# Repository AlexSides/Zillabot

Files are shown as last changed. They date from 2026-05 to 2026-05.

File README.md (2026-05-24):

# ZillaBot Senior Design Portfolio

ZillaBot is an autonomous senior design robot built for sumo-style pushing and tug-of-war competition. The robot combines a two-wheel rear-drive platform, floor-facing boundary sensors, front-facing time-of-flight sensors, IMU feedback, a custom CAD chassis, and an integrated PCB to support real-time navigation decisions.

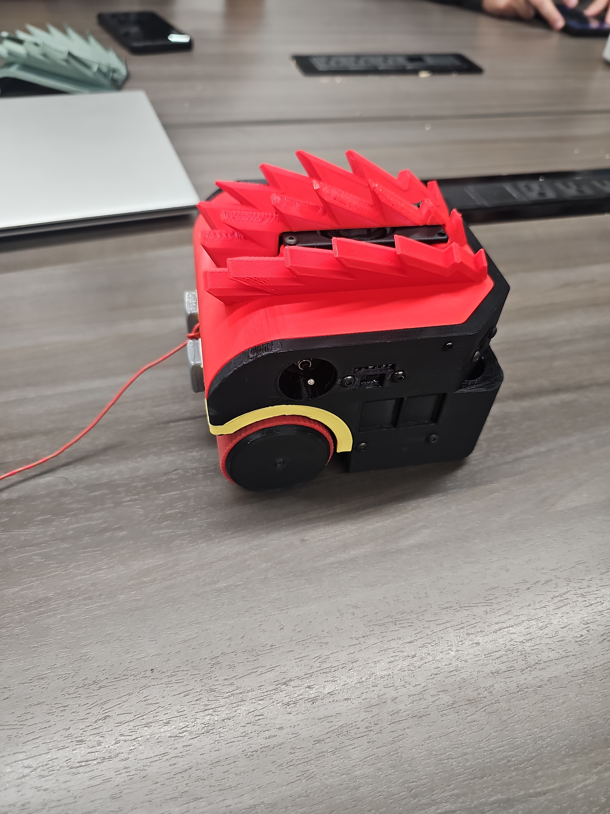
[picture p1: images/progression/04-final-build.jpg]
Final ZillaBot build


## What This Repository Shows

- Autonomous robot design for sumo and tug-of-war match formats
- Mechanical progression from breadboard prototype to enclosed 3D-printed robot
- Sensor-driven navigation using boundary, object-detection, and orientation inputs
- PCB, CAD, and chassis assets from the senior design build
- Test evidence, demo videos, and selected code examples

## Project Highlights

| Area | Evidence |
| --- | --- |
| Final robot build | [Build progression gallery](docs/media-gallery.md) |
| Demo footage | [Video evidence](docs/media-gallery.md#demo-videos) |
| Chassis and enclosure design | [Hardware assets](docs/hardware-assets.md) |
| PCB and wiring architecture | [PCB layout image](images/design/pcb-layout.png) and [Gerber package](hardware/pcb/zillabot-gerber.zip) |
| Architecture diagrams | [Rendered system and state diagrams](docs/architecture-diagrams.md) |
| Bill of materials | [BOM and cost summary](docs/bill-of-materials.md) |
| Navigation design | [Navigation subsystem](docs/navigation-subsystem.md), [state machine snippet](code-snippets/navigation-state-machine.md), and [source walkthrough](docs/source-code-walkthrough.md) |
| Testing summary | [Testing results](docs/testing-results.md) |

## Testing Evidence

The [testing results](docs/testing-results.md) page summarizes available subsystem, demo, and traction/push-test evidence. The revised tighter and thicker silicone tread improved push-test pass rates across the tested loads, though the new tread results used a smaller sample size and should be read with that limitation in mind.

## Key Engineering Takeaways

- Stronger traction can improve pushing force but also changes navigation behavior.
- Boundary detection needs to remain the highest-priority safety behavior.
- Live telemetry made sensor and state debugging easier during integration.
- Dual-core organization helped separate fast safety/motor behavior from higher-level navigation.
- Real-world robot testing revealed issues that were not obvious from code alone.

## Visual Design Progression

| Prototype wiring | Integrated prototype | Final enclosure |
| --- | --- | --- |
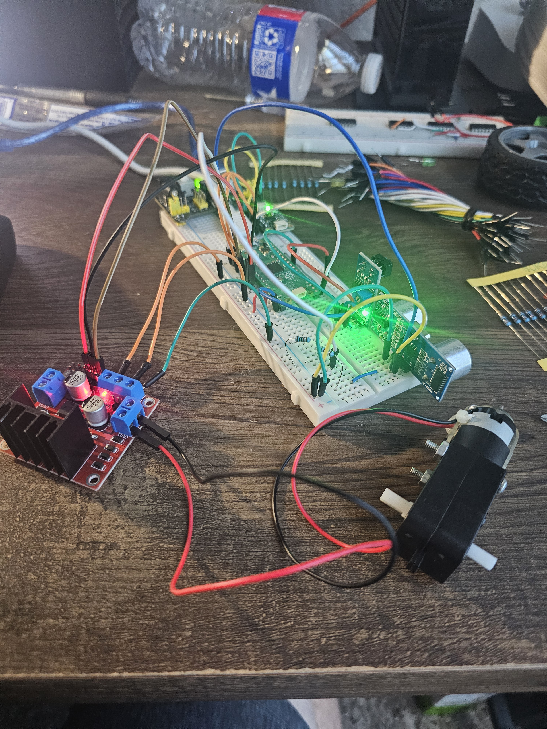
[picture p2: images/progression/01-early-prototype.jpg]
Early breadboard prototype
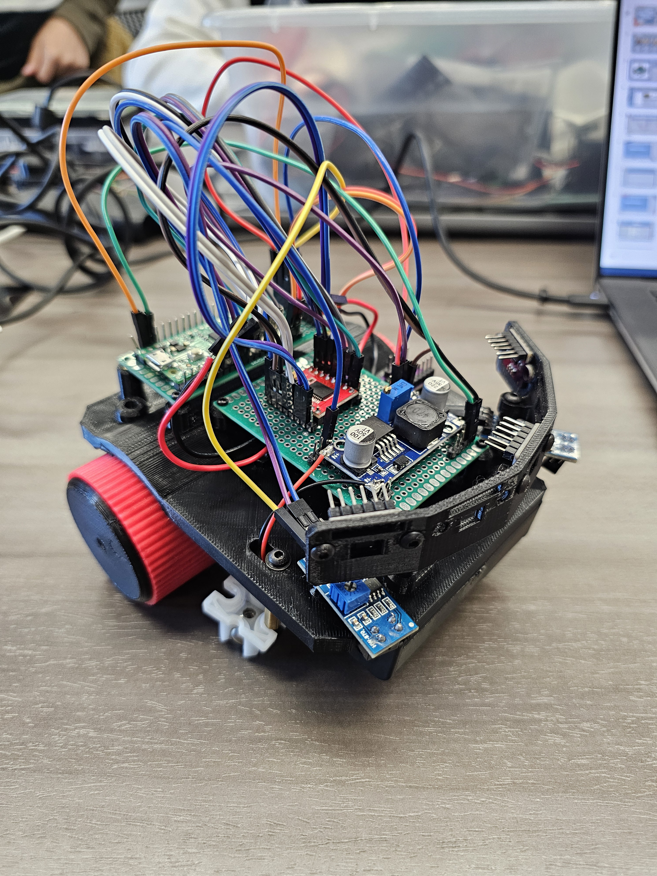
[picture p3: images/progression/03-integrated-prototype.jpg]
Integrated prototype
|  |  | Final enclosed ZillaBot |

## Repository Structure

- `docs/` contains the project overview, subsystem writeups, media gallery, hardware asset index, testing notes, and reflection.
- `images/` contains build photos, CAD renders, PCB imagery, chassis revisions, architecture diagrams, and testing visuals.
- `videos/` contains short demo clips.
- `hardware/` contains selected CAD, drawing, and PCB fabrication assets.
- `code-snippets/` contains portfolio-friendly excerpts that explain important logic.
- Root Python files contain the public project source snapshot included with this portfolio.

## Demo Videos

- [April 13 demo run](videos/2026-04-13-demo-run.mp4)
- [May 10 competition run](videos/2026-05-10-competition-run.mp4)
- [Short demonstration clip](videos/short-demo-clip.mp4)

## Current Status

This repository contains the public project source snapshot, selected hardware assets, photos, demo videos, and documentation from the ZillaBot senior design build. Some performance areas were documented qualitatively when formal measured data was not available.

## Wi-Fi Secrets

This repo does not track `wifi_secrets.py`.

Create a local `wifi_secrets.py` from `wifi_secrets.example.py` only when you are ready to run telemetry locally.

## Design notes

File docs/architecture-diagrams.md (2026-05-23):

# Architecture Diagrams

This page provides GitHub-viewable PNG versions of the system and navigation diagrams. The PNGs are exported from the D2 project-management and design-review materials.

The original editable sources remain available here:

- [IDR / design-review Draw.io source](../diagrams/idr-presentation.drawio)
- [Poster Draw.io source](../diagrams/poster.drawio)

## Top-Level System

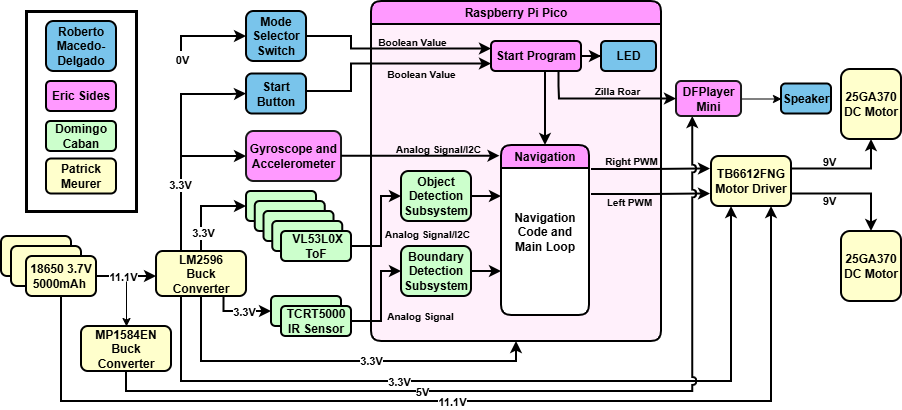
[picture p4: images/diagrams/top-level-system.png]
Top-level ZillaBot system diagram


## Power Block Diagram

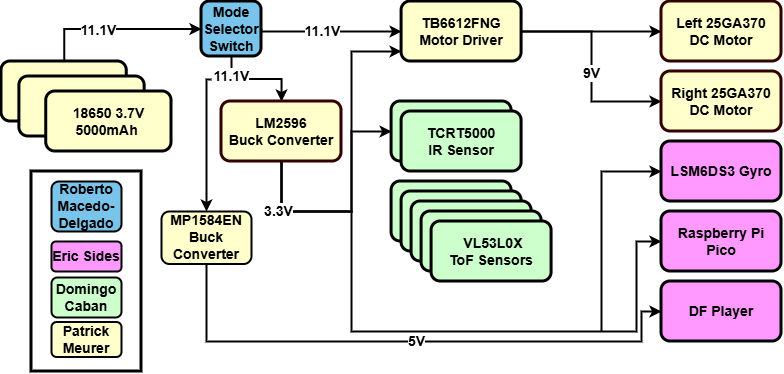
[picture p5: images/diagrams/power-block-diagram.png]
ZillaBot power block diagram


## Motor Control Diagram

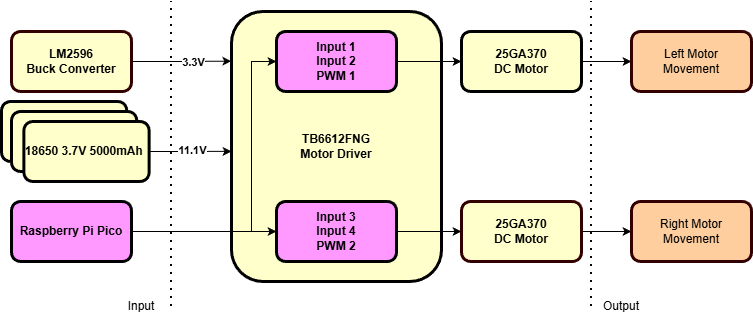
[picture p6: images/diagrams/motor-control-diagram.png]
ZillaBot motor control diagram


## Sensor Subsystem Diagrams

| Boundary Detection | Object Detection |
| --- | --- |
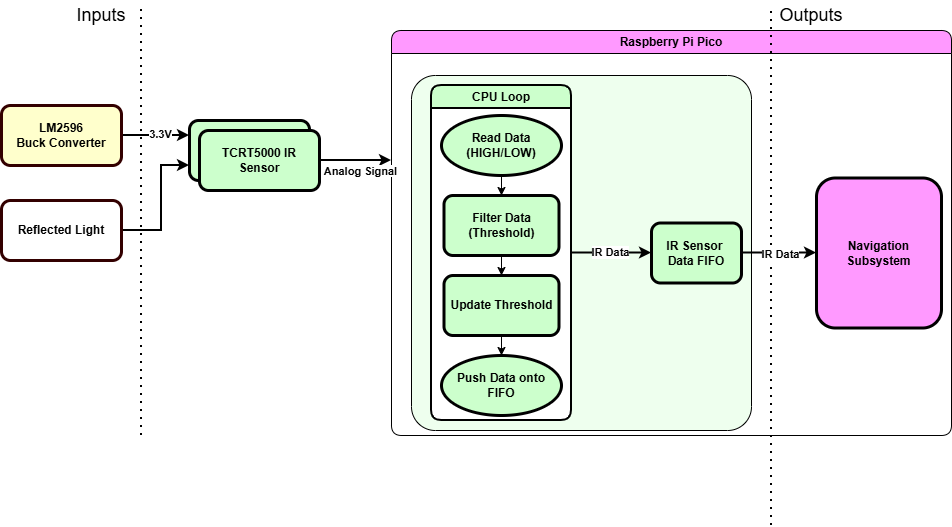
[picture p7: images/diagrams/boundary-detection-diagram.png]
Boundary detection diagram
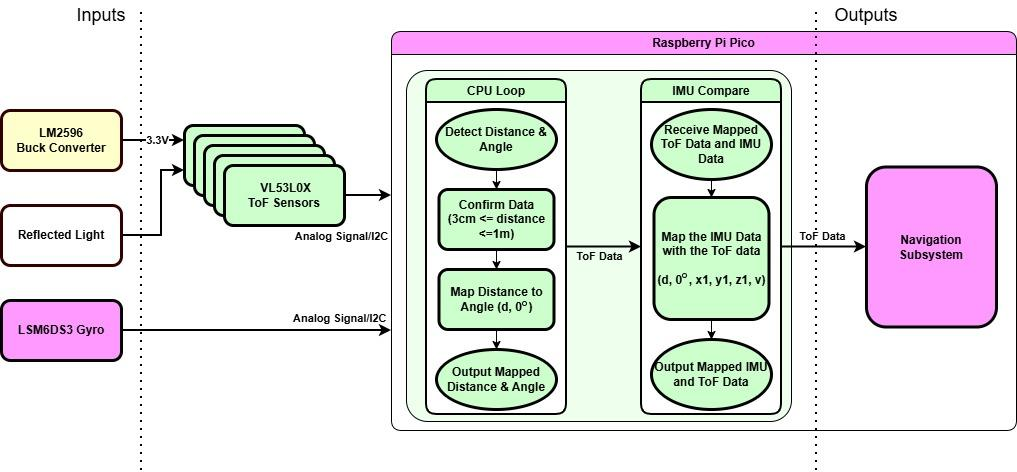
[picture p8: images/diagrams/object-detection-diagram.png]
Object detection diagram
|  |  |

## Navigation Block Diagram

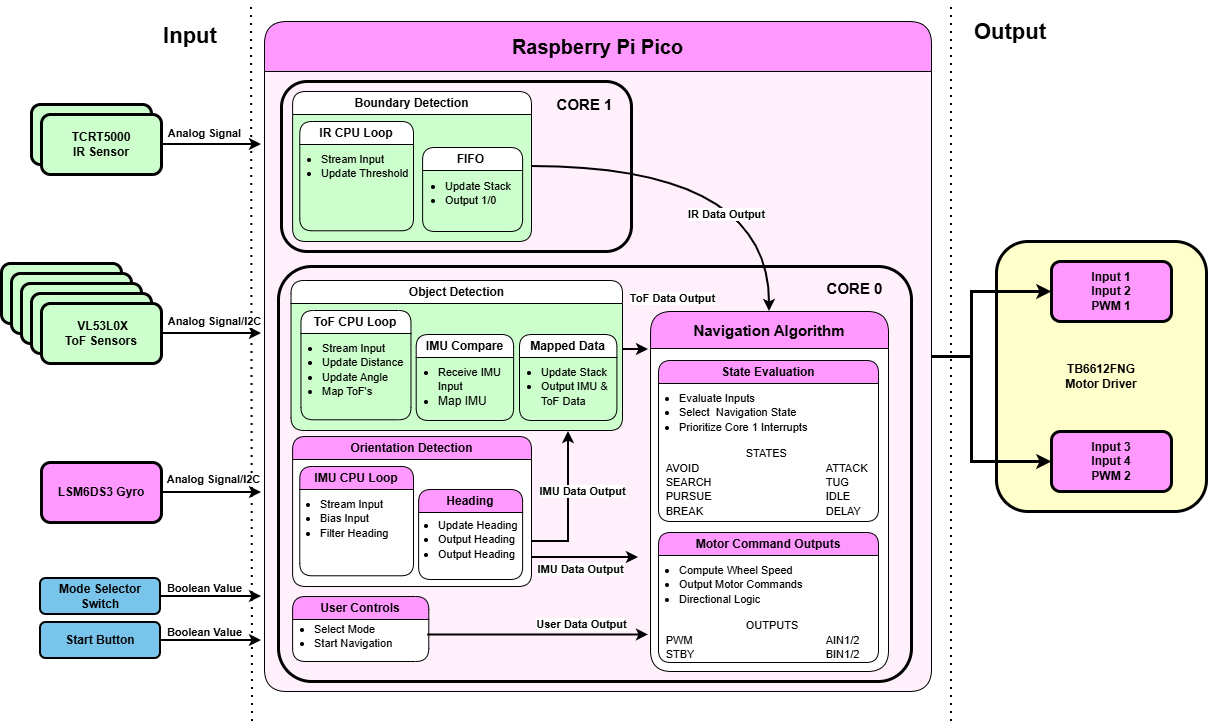
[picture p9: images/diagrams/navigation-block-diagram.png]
ZillaBot navigation block diagram


## Navigation State Diagrams

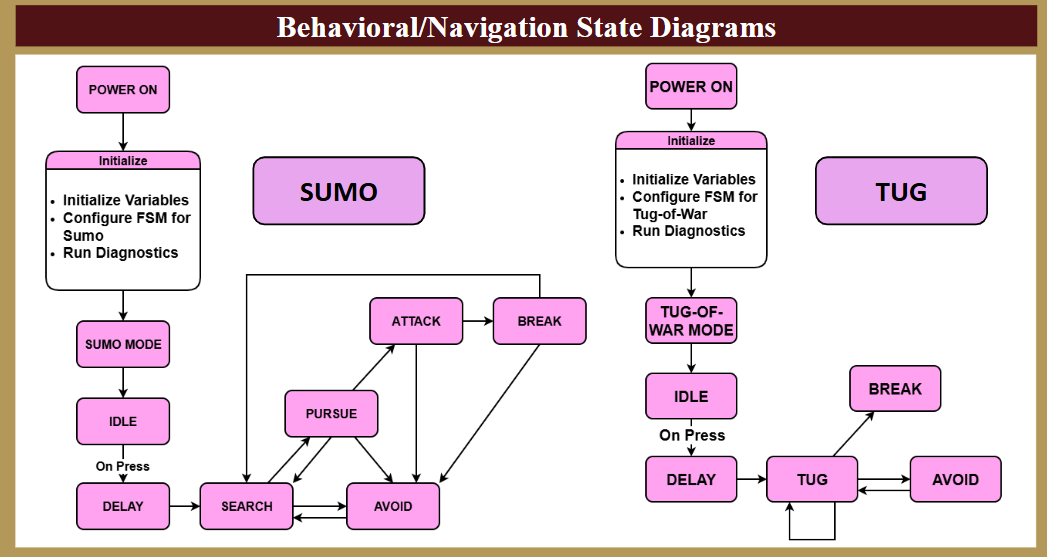
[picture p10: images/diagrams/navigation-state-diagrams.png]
ZillaBot navigation state diagrams


## Telemetry Wireframe

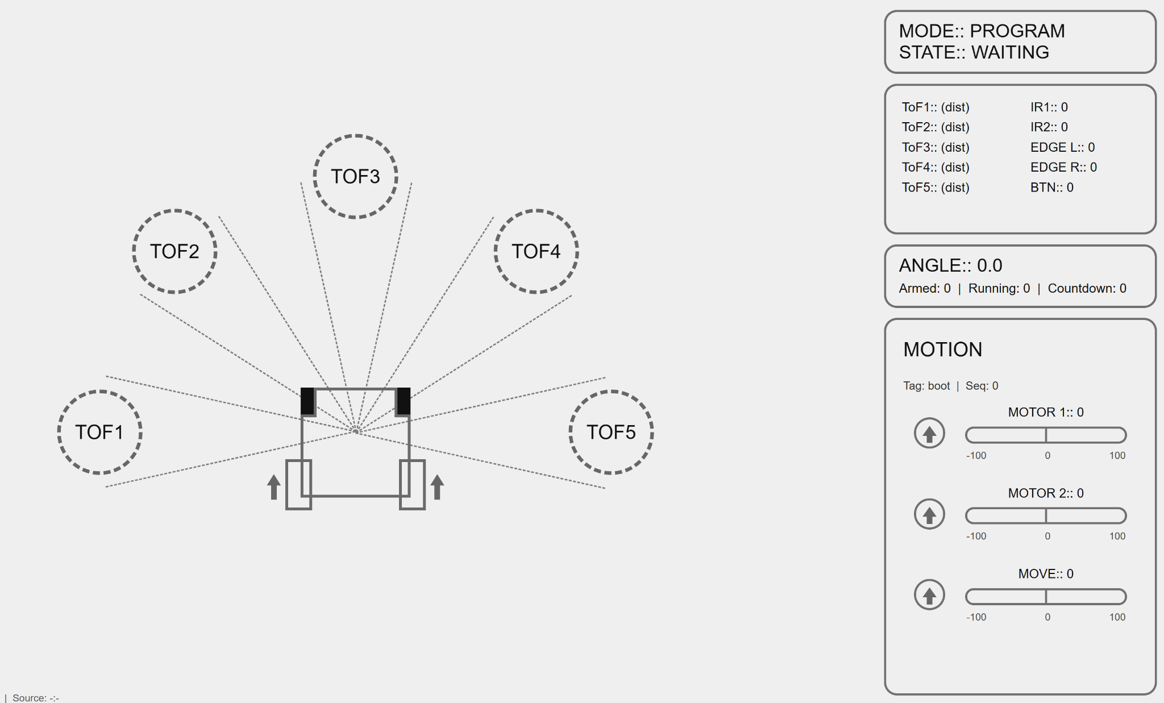
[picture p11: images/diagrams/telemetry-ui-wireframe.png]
ZillaBot telemetry UI wireframe


## Notes

- These images are intended for quick public viewing on GitHub and preserve the original design-review visual style.
- The Draw.io files are kept as the editable design-review sources.
- The diagrams are documentation artifacts and should be read alongside the source-code walkthrough and testing results.

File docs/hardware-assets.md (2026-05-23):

# Hardware Assets

This page indexes the selected CAD, PCB, drawing, and diagram assets included in the portfolio repository.

## CAD and 3D-Printed Parts

| File | Purpose |
| --- | --- |
| [final-chassis.stl](../hardware/cad/final-chassis.stl) | Final chassis model |
| [final-enclosure.stl](../hardware/cad/final-enclosure.stl) | Final enclosure model |
| [motor-mount-left.step](../hardware/cad/motor-mount-left.step) | Left motor mount |
| [motor-mount-right.step](../hardware/cad/motor-mount-right.step) | Right motor mount |
| [poly-wheel.step](../hardware/cad/poly-wheel.step) | Wheel component model |
| [silicone-wheel.step](../hardware/cad/silicone-wheel.step) | Wheel component model |
| [battery-cover.step](../hardware/cad/battery-cover.step) | Battery cover model |

## PCB and Electrical Design

| File | Purpose |
| --- | --- |
| [zillabot-gerber.zip](../hardware/pcb/zillabot-gerber.zip) | PCB fabrication Gerber package |
| [pcb-layout.png](../images/design/pcb-layout.png) | PCB and subsystem layout image |
| [bill-of-materials.md](bill-of-materials.md) | D2 final design review BOM and unit-cost summary |

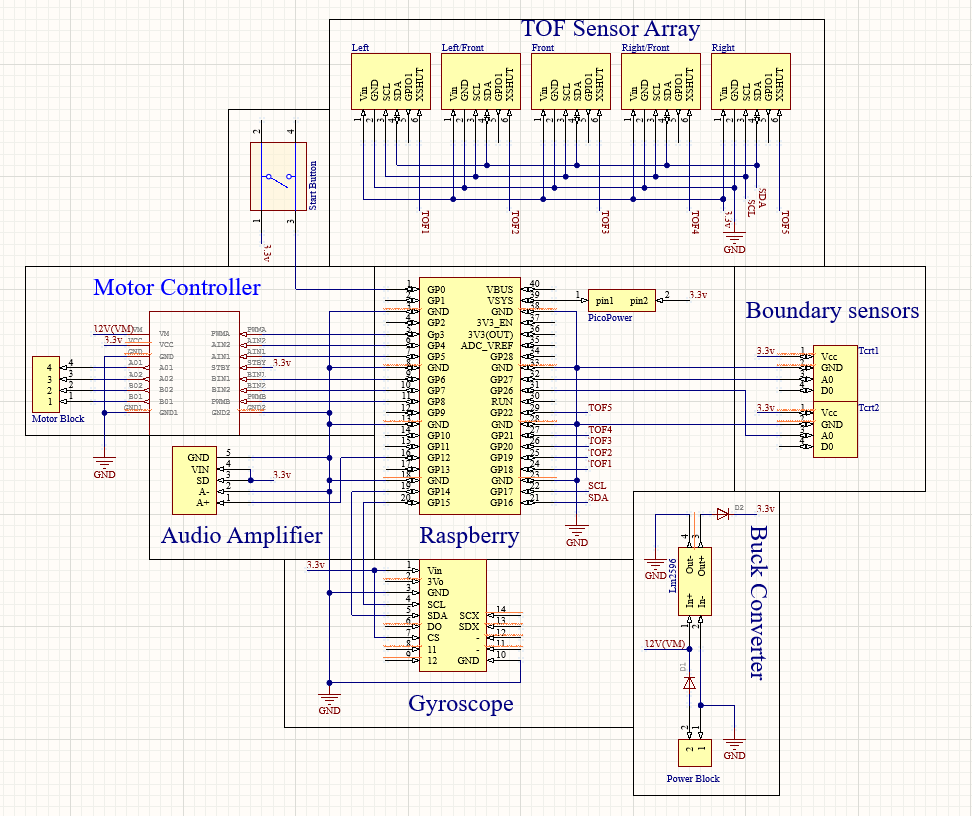
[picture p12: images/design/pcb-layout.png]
PCB layout


## Drawings and Diagrams

| File | Purpose |
| --- | --- |
| [chassis-v5-drawing.svg](../hardware/drawings/chassis-v5-drawing.svg) | Chassis engineering drawing |
| [idr-presentation.drawio](../diagrams/idr-presentation.drawio) | Design-review diagram source |
| [poster.drawio](../diagrams/poster.drawio) | Poster diagram source |
| [architecture-diagrams.md](architecture-diagrams.md) | Rendered PNG versions of system and navigation diagrams |

## Chassis Revision Images

| Revision | Preview |
| --- | --- |
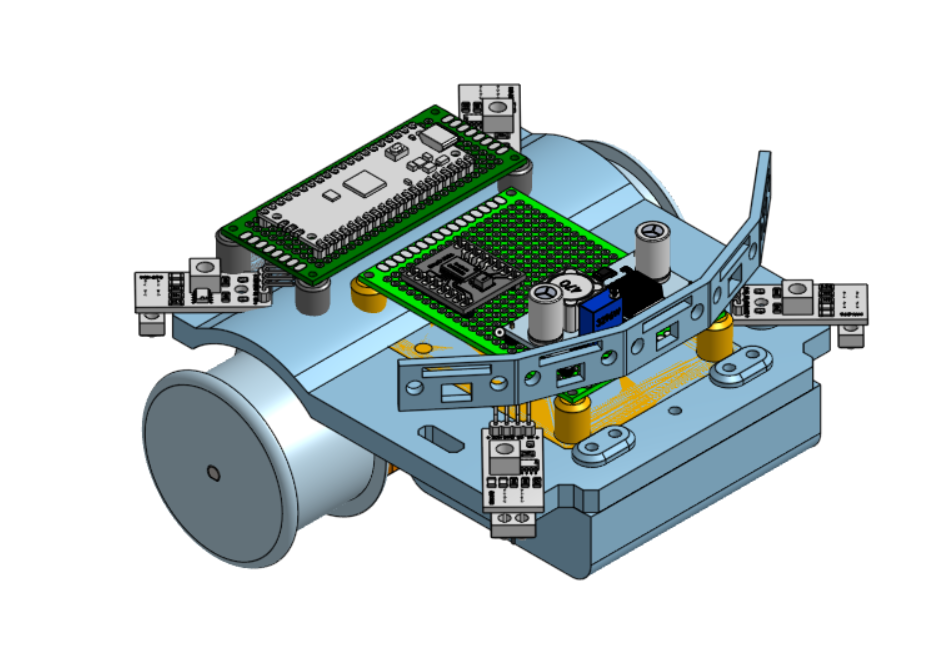
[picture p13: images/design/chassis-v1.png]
Chassis V1
| V1 |  |
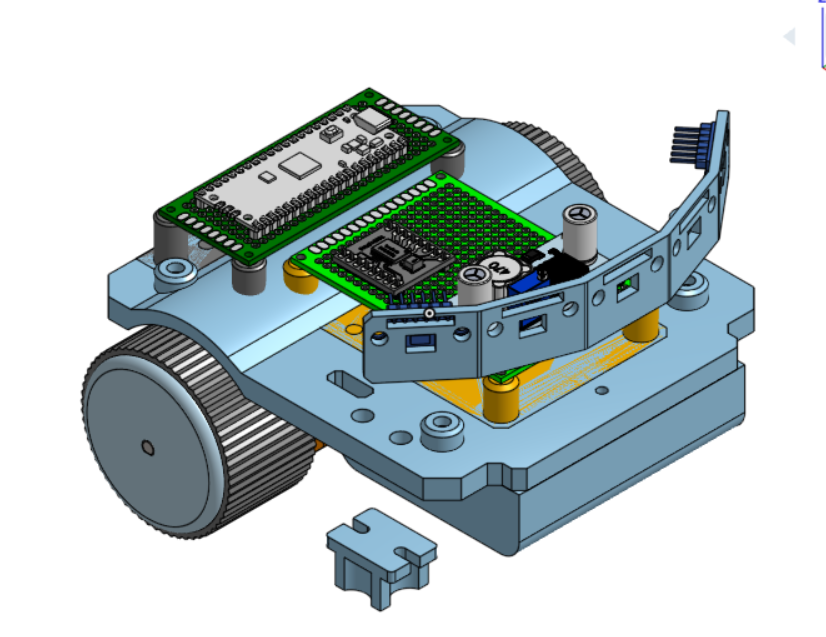
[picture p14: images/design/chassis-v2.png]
Chassis V2
| V2 |  |
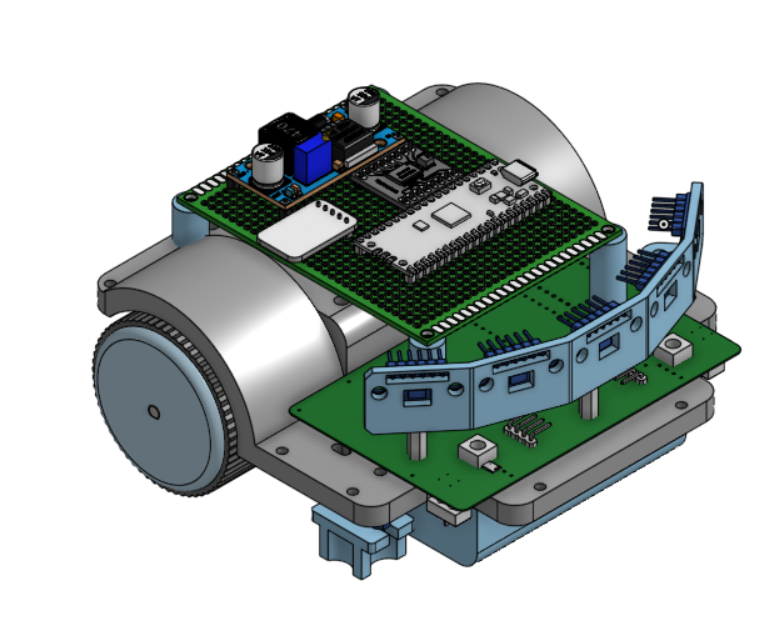
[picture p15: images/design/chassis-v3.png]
Chassis V3
| V3 |  |
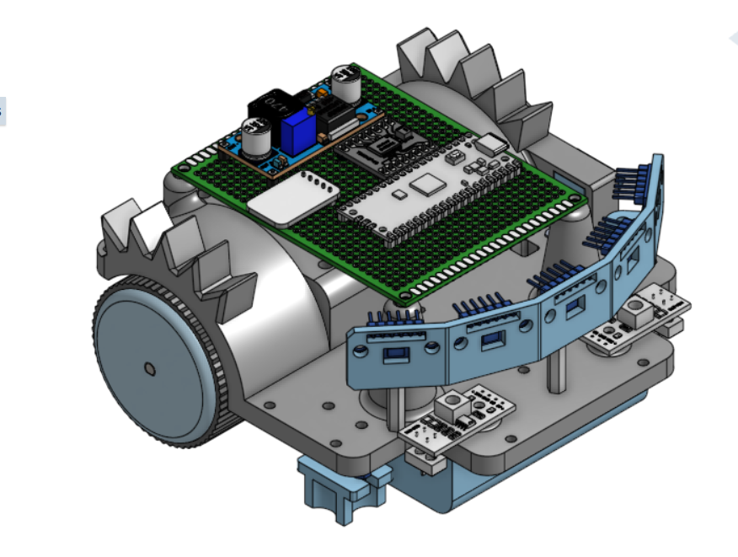
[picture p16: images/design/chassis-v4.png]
Chassis V4
| V4 |  |
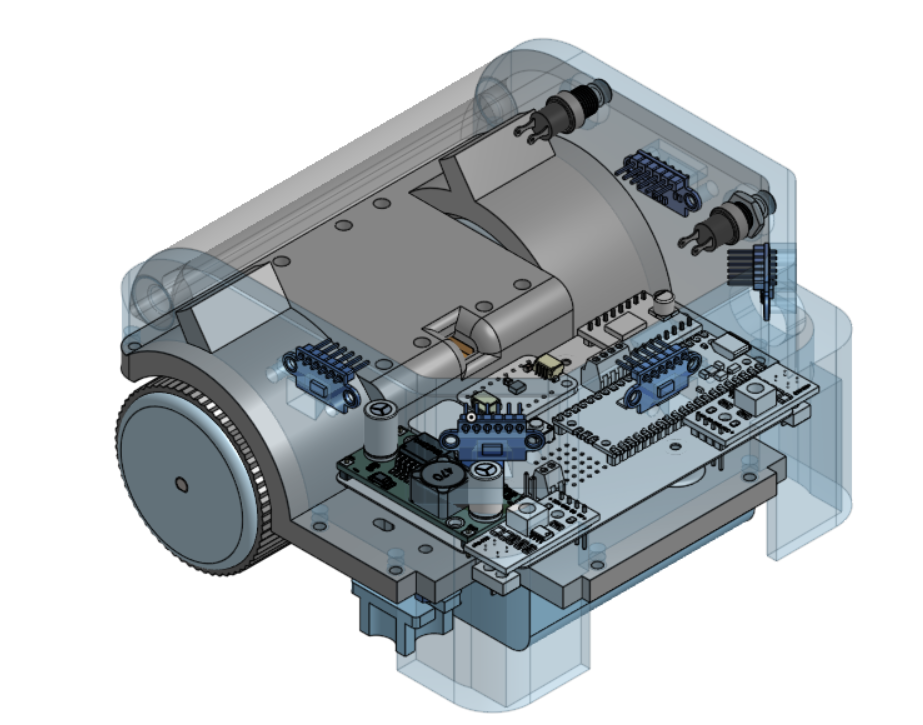
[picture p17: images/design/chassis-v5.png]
Chassis V5
| V5 |  |
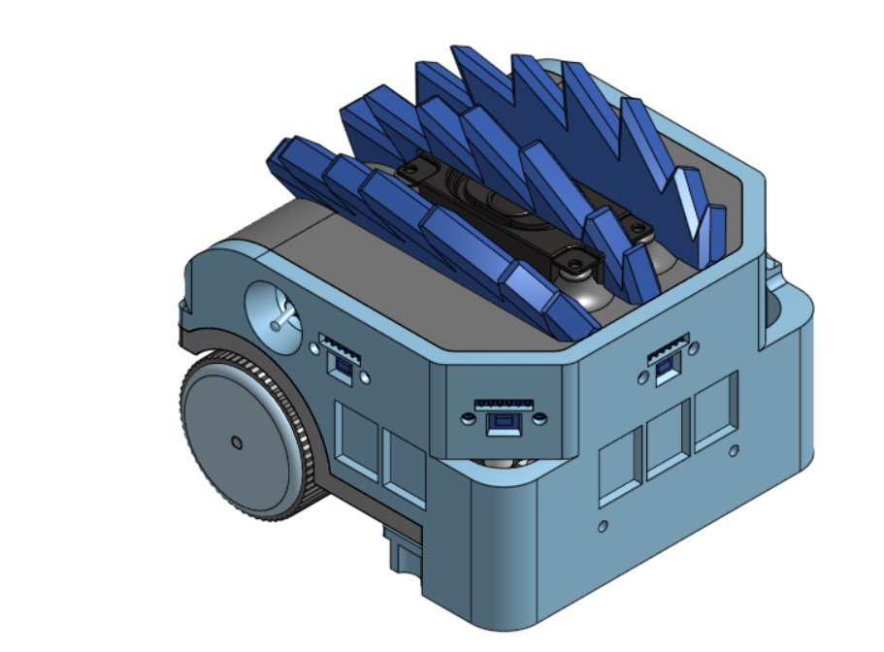
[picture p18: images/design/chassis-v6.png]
Chassis V6
| V6 |  |
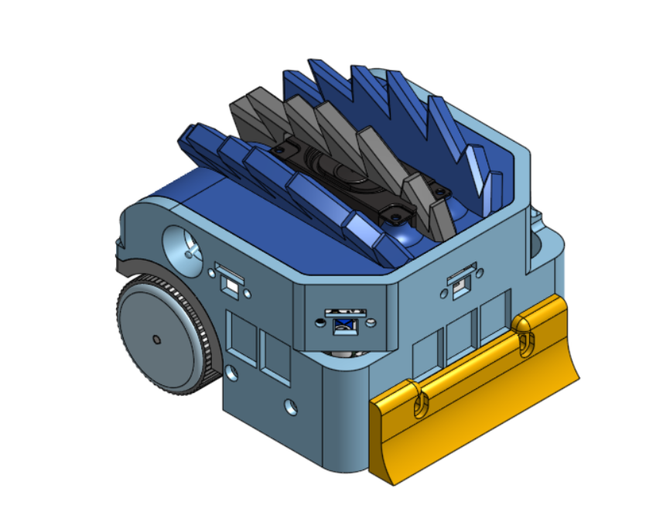
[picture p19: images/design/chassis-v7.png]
Chassis V7
| V7 |  |

## Notes

The selected hardware files show the public CAD, drawing, diagram, and PCB artifacts available for the portfolio. Specific CAD software versions, printer settings, PCB toolchain details, and revision-by-revision design notes are not formally documented in the available public records.

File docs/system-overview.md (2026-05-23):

# System Overview

## Project Summary

ZillaBot is an autonomous robot designed for sumo and tug-of-war style competition. The platform was built to detect arena boundaries, identify nearby objects or opponents, and choose movement responses without direct human control during a match.

The final system combines a two-wheel rear-drive layout, floor-facing boundary detection sensors, front-facing time-of-flight sensors, IMU feedback, motor control hardware, a custom CAD chassis, and an integrated PCB.

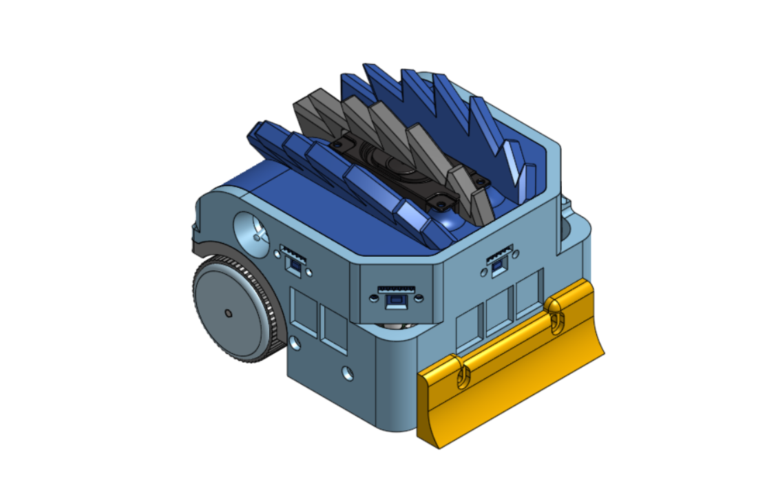
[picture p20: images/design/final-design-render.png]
Final CAD design render


## Core Objectives

- Build a mobile robot platform with reliable sensing and motion control
- Support autonomous decision-making during matches or trials
- Integrate hardware and software into one repeatable system
- Demonstrate the design process, testing process, and final lessons learned

## High-Level Architecture

ZillaBot can be described as a set of connected subsystems:

- Mechanical subsystem: 3D-printed chassis, enclosure, wheel components, motor mounts, and front attachment geometry
- Electrical subsystem: microcontroller, motor driver, buck converter, audio amplifier, gyroscope, boundary sensors, and time-of-flight sensor array
- Software subsystem: sensor polling, mode selection, navigation state logic, motor command generation, and optional telemetry support

The D2 design-review materials describe the final robot as a set of sensing, decision, motor, power, PCB, and chassis subsystems working together around the Raspberry Pi Pico controller.

```mermaid
flowchart LR
    start["Start button and mode selector"] --> pico["Raspberry Pi Pico"]
    ir["2x TCRT5000 boundary sensors"] --> pico
    tof["5x VL53L0X ToF sensors"] --> pico
    imu["LSM6DS3 IMU"] --> pico
    pico --> nav["Navigation state logic"]
    nav --> motor["TB6612FNG motor driver"]
    motor --> wheels["2x 25GA370 drive motors"]
    battery["3x 18650 battery pack"] --> buck["LM2596 buck converter"]
    battery --> motor
    buck --> pico
    buck --> ir
    buck --> tof
```

## System Diagram

Top-level system diagram

PCB and subsystem layout

Additional design source files are available in:

- [Architecture diagrams](architecture-diagrams.md)
- [Hardware assets](hardware-assets.md)
- [Media gallery](media-gallery.md)
- [Draw.io diagrams](../diagrams/)

## Major Subsystems

### Mobility

The robot uses a two-wheel rear-drive approach. The navigation software commands differential wheel movement to search, turn, pursue, recover, and drive during competition behavior.

### Sensing

The sensing system combines several inputs:

- floor-facing boundary sensors for arena edge detection
- front-facing time-of-flight sensors for object and opponent detection
- IMU feedback for orientation and heading-related behavior

### Navigation and Decision Logic

The navigation layer uses sensor priority rules and state-based behavior. Boundary and safety conditions take priority, while target detection and pursuit behavior guide the robot during active match modes.

### User Interface or Match Controls

The implementation includes mode selection and startup handling for match-oriented operation. The available public records do not include a finished control-panel diagram, so this section stays at the system-behavior level.

## Design Constraints

The project was shaped by senior design deadlines, competition-style operation, hardware integration limits, and the need for repeatable demonstrations.

- Size limit: 13 cm by 13 cm footprint, with unrestricted height in the competition requirements documented in the D2 materials
- Time constraints: senior design schedule and demonstration deadlines
- Budget constraint: $75 original unit-cost requirement; the final design-review BOM listed a $74.93 unit cost
- Reliability requirements: repeatable startup, stable movement, and reliable boundary detection
- Competition rules or environment: sumo arena and tug-of-war match conditions

## Final Notes

This page is the top-level technical summary. The deeper pages document navigation behavior, testing evidence, hardware assets, and project reflection.

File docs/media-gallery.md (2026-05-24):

# Media Gallery

This page collects the visual evidence for ZillaBot's build progression, design iteration, and demonstration runs.

## Build Progression

| Stage | Image | What It Shows |
| --- | --- | --- |
| Early electronics prototype | Early breadboard prototype | Microcontroller, motor driver, sensor, and power testing on a breadboard setup |
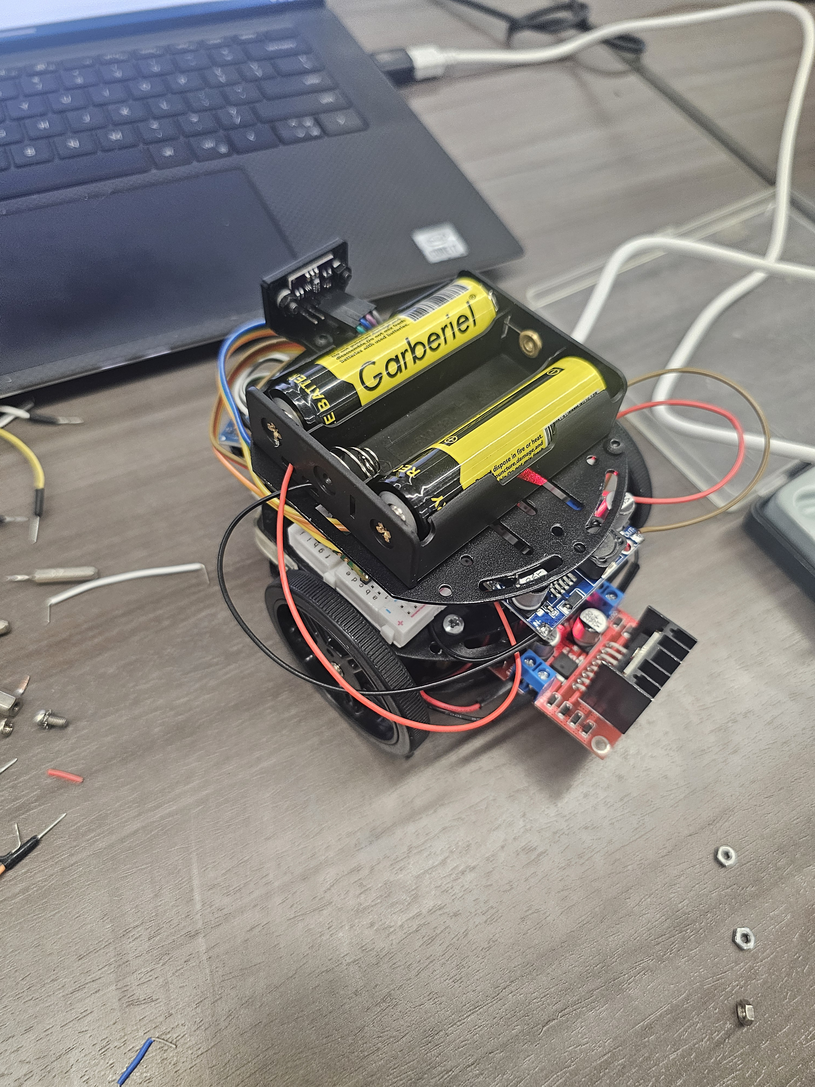
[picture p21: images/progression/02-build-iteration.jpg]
First mobile prototype
| First mobile prototype |  | Battery, motor driver, drivetrain, and early mobile wiring integration |
| Integrated prototype | Integrated prototype | 3D-printed chassis with mounted electronics and sensor wiring |
| Final enclosed robot | Final enclosed robot | Final exterior form with front attachment and enclosed body |

## Design and CAD References

| Asset | Preview |
| --- | --- |
| Final CAD render | Final CAD render |
| PCB and subsystem layout | PCB layout |
| Chassis V7 render | Chassis V7 |

The full CAD and PCB file index is in [Hardware Assets](hardware-assets.md).

## Demo Videos

- [April 13 demo run](../videos/2026-04-13-demo-run.mp4)
- [May 10 competition run](../videos/2026-05-10-competition-run.mp4)
- [Short demonstration clip](../videos/short-demo-clip.mp4)

## Testing Visuals

- [Arena setup photo](../images/testing/build-test-setup.jpg)
- [TCRT distance reference](../images/testing/tcrt-distance.png)
- [FDR IR reflectivity graph](../images/testing/fdr-ir-reflectivity-full-trial.png)
- [FDR ToF distance graph](../images/testing/fdr-tof-center-distance.png)
- [FDR live telemetry screenshot](../images/testing/fdr-live-telemetry-feed.png)

## Notes

The gallery uses the strongest public visuals currently available in this repository. Additional labeled wiring photos, team photos, or competition-day images can be added later if they are approved for public sharing.

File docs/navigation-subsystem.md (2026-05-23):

# Navigation Subsystem

## Purpose

The navigation subsystem determines how ZillaBot interprets sensor input and chooses movement actions in real time. Its goal is to keep the robot responsive during sumo and tug-of-war behavior while protecting against arena boundary conditions.

## Navigation Responsibilities

- Read and combine sensor information
- Identify the current operating situation
- Choose the next action or movement state
- Send movement intent to the motor control layer

## Inputs

- front-facing time-of-flight readings for opponent or object detection
- floor-facing boundary sensor readings for edge detection
- IMU values for orientation feedback
- mode selection inputs for switching between program, sumo, and tug behavior
- start input used before entering active match behavior

## Outputs

- movement intent sent to the motor control layer
- navigation state changes such as search, pursue, avoid, or tug behavior
- telemetry/debug outputs when enabled for testing

## Navigation Strategy

- Search behavior: move or turn until the sensor array identifies a meaningful target condition
- Pursuit behavior: drive toward a detected object or opponent using front sensor readings
- Avoid or recovery behavior: prioritize edge detection and reverse/turn behavior before continuing
- Mode-specific behavior: support different competition behavior for sumo and tug-of-war operation
- Break or protective stop behavior: stop/retry behavior is used when the robot stalls or remains immobile long enough to risk motor stress

## Final Configuration Evidence

The D2 final design review documented the tuned navigation configuration values below. These values are included as project evidence, not as a guarantee that every future run will behave identically under different floor, battery, or traction conditions.

| Behavior Area | Documented Setting | Result |
| --- | --- | --- |
| Boundary thresholds | Left: 38200, Right: 37400 | PASS |
| ToF detection range | 1000 mm | PASS |
| Search behavior | Turn: 0.22 s, Burst: 0.15 s, Speed: 0.4 | PASS |
| Avoid behavior | Reverse: -0.6 for 0.6 s, Turn: 0.2 for 0.2 s | PASS |
| Pursuit behavior | Base: 0.6, Attack: 0.8, Align: 0.9 | PASS |
| IMU turning | Filter: 0.10, Turn speed: 0.8 | PASS |

## State Machine Summary

Navigation block diagram

The current portfolio snippet describes the state-machine concept here:

- [Navigation state machine snippet](../code-snippets/navigation-state-machine.md)
- [Design-review Draw.io diagrams](../diagrams/idr-presentation.drawio)
- [Rendered architecture diagrams](architecture-diagrams.md)

The design-review Draw.io source includes navigation block and state diagrams for the portfolio record. The linked snippet provides a readable summary of the same design approach: read sensors, prioritize safety conditions, choose a navigation state, and send movement commands.

Sumo and tug navigation state diagrams

## Sensor Fusion and Priority Rules

Boundary and safety-related readings should be treated as higher priority than pursuit behavior. This keeps the robot from continuing an aggressive movement when an edge or unsafe condition has been detected.
The D2 navigation materials identify states including idle, delay, search, pursue, attack, avoid, break, and tug behavior. They also describe state evaluation as the point where sensor inputs are evaluated, a navigation state is selected, and fast safety-related conditions are prioritized.

## Known Challenges

- sensor readings can vary with surface, distance, and robot angle
- state transitions need to be fast enough for competition behavior
- motor response, battery level, and floor traction can change the observed behavior
- telemetry is helpful for debugging but should not slow down the control loop

## Remaining Limits in the Public Record

- Full replay plots from telemetry logs are not included in this public repository.
- Behavior across multiple floor materials or battery states was not formally summarized as a public trial table.
- Higher speed settings improved response but increased self-ring-out risk, especially after the traction upgrade.

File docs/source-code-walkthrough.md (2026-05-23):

# Source Code Walkthrough

This page explains how the public ZillaBot source snapshot is organized. It focuses on the main runtime path across sensing, navigation, and motor output.

## Runtime Flow

ZillaBot separates fast sensor updates, decision logic, and motor commands into small modules:

```mermaid
flowchart LR
    main["main.py"] --> sensors["core0_sensors.py"]
    sensors --> shared["Shared sensor state"]
    shared --> nav["core1_navigation.py"]
    nav --> motor["core0_motor.py"]
    motor --> driver["TB6612FNG + drive motors"]
    nav --> telemetry["nav_state telemetry"]
```

## Startup and Mode Control

[main.py](../main.py) is the runtime entry point. It initializes the motor layer, starts the sensor core, reads the physical mode switch, waits for required sensors to become ready, and starts the selected match behavior after the start button and countdown.

The three user-facing modes are defined in [config.py](../config.py):

| Mode | Purpose |
| --- | --- |
| `MODE_PROGRAM` | Safe/programming mode where match behavior does not run |
| `MODE_1_SUMO` | Sumo behavior using boundary avoidance and target pursuit |
| `MODE_2_TUG` | Tug-of-war behavior using heading correction and line handling |

## Sensor Layer

[core0_sensors.py](../core0_sensors.py) owns the shared sensor dictionaries used by the rest of the robot:

| Shared State | Main Contents | Used For |
| --- | --- | --- |
| `boundary_state` | Raw IR values plus sumo/tug boundary flags | Edge detection and tug line behavior |
| `tof_state` | Per-sensor ToF distance readings and minimum valid distance | Opponent/object targeting |
| `imu_state` | Heading, turn-rate values, bias calibration, and IMU readiness | Turn control and tug heading correction |
| `sensor_runtime_state` | Sensor-loop status and last update time | Startup readiness checks |

The sensor thread reads the two TCRT5000 boundary sensors through ADC, initializes and polls the VL53L0X ToF array, and integrates LSM6DS3 gyro readings into a heading estimate. Optional CSV logging exists for test sessions, but it is disabled by default in [config.py](../config.py) so flash writes do not slow the match loop.

## Navigation Layer

[core1_navigation.py](../core1_navigation.py) reads the shared sensor state and selects movement behavior. It also maintains `nav_state`, a telemetry-friendly snapshot containing the current mode, state name, best target sensor, edge flags, heading values, and ToF readings.

### Sumo Behavior

`run_mode_1_sumo()` is the main sumo loop. Its priority order is:

1. Confirm boundary/edge readings before committing to avoidance.
2. Reverse and turn away from the edge using IMU-assisted turning.
3. Search forward when no valid target is detected.
4. Pursue left or right when a side ToF sensor sees the closest target.
5. Increase attack behavior when the center ToF sensor is locked on a close target.
6. Use shoulder-break behavior when the robot appears stuck against a close target.

This structure matches the project takeaway that boundary detection must stay higher priority than aggressive pursuit.

### Tug-of-War Behavior

`run_mode_2_tug_once()` drives the tug behavior. It stores the starting heading, compares the live heading against that target, and applies a proportional correction to the left and right wheel commands. If one boundary sensor sees a line long enough, the code can bias recovery toward the opposite side. If both sensors detect the dark stop condition long enough, the robot stops.

## Motor Layer

[core0_motor.py](../core0_motor.py) converts normalized wheel commands into TB6612FNG direction pins and PWM duty cycles. The main public functions are:

| Function | Behavior |
| --- | --- |
| `stop()` | Disables both wheel outputs |
| `forward(speed)` | Drives both wheels forward |
| `reverse(speed)` | Drives both wheels backward |
| `turn_left(speed)` | Spins left by reversing the left wheel and driving the right wheel |
| `turn_right(speed)` | Spins right by driving the left wheel and reversing the right wheel |
| `set_wheels(left_speed, right_speed)` | Sends independent normalized commands to each wheel |

The motor module also updates `motor_state`, which keeps the latest left/right command values available for telemetry or debugging.

## Configuration

[config.py](../config.py) centralizes pins, thresholds, feature flags, and behavior tuning values. Important examples include:

- motor PWM and direction pins
- IR ADC pins and boundary thresholds
- ToF XSHUT pins, I2C addresses, and logical sensor names
- IMU pins and heading filter
- sumo search, avoid, pursuit, attack, and shoulder-break tuning
- tug heading correction and edge-recovery tuning

## Engineering Takeaway

The code is organized around a practical embedded robotics pattern: collect sensor state continuously, make state-machine decisions from that shared state, and keep motor output functions small and predictable. That organization made it easier to tune traction, pursuit, avoidance, and tug behavior without mixing every hardware detail into one file.

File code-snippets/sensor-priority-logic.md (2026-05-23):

# Sensor Priority Logic Snippet

This page is for a small portfolio excerpt that demonstrates how ZillaBot resolves competing sensor inputs.

## Representative Pseudocode

```text
if edge_sensor_triggered:
    perform_escape_behavior()
else if opponent_in_range:
    move_to_engage()
else if heading_is_uncertain:
    stabilize_or_recenter()
else:
    continue_search_pattern()
```

## Why This Matters

- Safety-related sensor inputs should override aggressive movement
- Priority rules make robot behavior easier to explain and debug
- This logic shows how the robot avoids reacting to every sensor equally

## Notes

This pseudocode is a public-facing explanation of the priority concept. The available public records do not include a complete formal sensor-priority table.

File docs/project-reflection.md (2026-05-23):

# Project Reflection

## Project Reflection Summary

ZillaBot was a multidisciplinary senior design project that required mechanical design, embedded software, electrical integration, testing, and public presentation work. This reflection is based on the public project materials in the repository rather than private team notes.

## What Went Well

- The project produced a visible design progression from early breadboard testing to a 3D-printed enclosed robot.
- The team separated major concerns into subsystems such as navigation, motor control, boundary detection, object detection, PCB/chassis design, and power.
- The repository now includes photos, videos, CAD assets, PCB assets, diagrams, and selected source files, which makes the project easier to understand outside the classroom.
- Telemetry and subsystem testing were used as part of the debugging and validation process.

## Biggest Challenges

- Integrating sensors, motors, power, wiring, and physical packaging into one compact robot was a central challenge.
- Navigation behavior depended on real-world conditions such as floor surface, sensor angle, target distance, and battery/motor response.
- The available records show multiple chassis and code iterations, which suggests that the final system required repeated design changes rather than a single clean build.
- Some performance data was not preserved in a public, measured format, which limits how precisely the final behavior can be summarized here.

## What You Learned

The project demonstrates practical learning in embedded programming, sensor integration, control logic, mechanical packaging, and test-driven iteration. It also shows the value of documenting design decisions as the build changes, especially when a project combines hardware, firmware, and physical competition constraints.

## What You Would Do Differently

- Keep a cleaner public test log with repeated trials, exact conditions, and measured results.
- Preserve labeled photos for each major hardware revision and wiring milestone.
- Create a formal state-transition diagram for the navigation subsystem.
- Separate public portfolio code from private/local configuration files earlier in the project.

## Team and Process Reflection

The public materials identify subsystem ownership across navigation, motor control/power, boundary detection, object detection, and PCB/chassis work. The project required those subsystem efforts to converge into a single robot that could be demonstrated in a competitive setting.

## Future Work

- Include final measured performance data if original logs or reports are recovered.
- Add a formal navigation state diagram and sensor-priority table.
- Add clearer captions for each chassis revision to explain what changed between versions.
- Add a concise bill of materials if public part and cost records are available.

## Closing Note

ZillaBot represents a complete senior design effort rather than a polished commercial product. Its value is in the engineering process: building, testing, redesigning, documenting, and integrating multiple subsystems into a working autonomous robot.

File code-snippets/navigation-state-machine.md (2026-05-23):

# Navigation State Machine Snippet

This page uses representative pseudocode to explain the navigation approach without publishing every implementation detail. It is intended to show the design pattern behind ZillaBot's state-based behavior.

## Representative Pseudocode

```text
state = IDLE

loop:
    read sensors

    if boundary_detected:
        state = AVOID
    else if target_detected:
        state = PURSUE
    else:
        state = SEARCH

    if state == SEARCH:
        rotate_or_scan()
    else if state == PURSUE:
        drive_toward_target()
    else if state == AVOID:
        reverse_and_turn()
```

## What This Snippet Shows

- state-based decision making
- priority of safety conditions
- separation between sensing and action selection

## Notes

The exact production state transitions are not fully documented in the public records. This simplified version is included to make the navigation concept readable for reviewers.

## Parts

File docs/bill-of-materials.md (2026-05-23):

# Bill of Materials and Cost Summary

This page summarizes the bill of materials documented in the D2 final design review. It is included as portfolio evidence for the major purchased components and the final unit-cost estimate.

The original unit-cost requirement listed in the final design review was $75.00 per robot. The documented total unit cost was $74.93.

| Component | Quantity | Price Each | Subtotal |
| --- | ---: | ---: | ---: |
| TCRT5000 IR sensor | 2 | $1.58 | $3.16 |
| VL53L0X ToF sensor | 5 | $2.97 | $14.85 |
| 25GA-370 DC 12V motor | 2 | $12.99 | $25.98 |
| Raspberry Pi Pico | 1 | $5.00 | $5.00 |
| Batteries | 3 | $1.12 | $3.36 |
| LM2596 buck converter | 1 | $4.23 | $4.23 |
| TB6612FNG motor driver | 1 | $5.95 | $5.95 |
| Battery holder | 1 | $0.60 | $0.60 |
| DFPlayer Mini and speaker | 1 | $6.00 | $6.00 |
| Silicone wheels | 4 | $0.45 | $1.80 |
| LSM6DS3 gyro | 1 | $6.00 | $4.00 |
| Total unit cost |  |  | $74.93 |

## Notes

- This table reflects the final design-review BOM, not a full manufacturing-ready sourcing package.
- Taxes, shipping, printing material, spare parts, and donated or reused lab materials may not be fully represented in the public cost summary.
- The `LSM6DS3 gyro` row is preserved as documented in the source slide, including the listed price/subtotal mismatch.

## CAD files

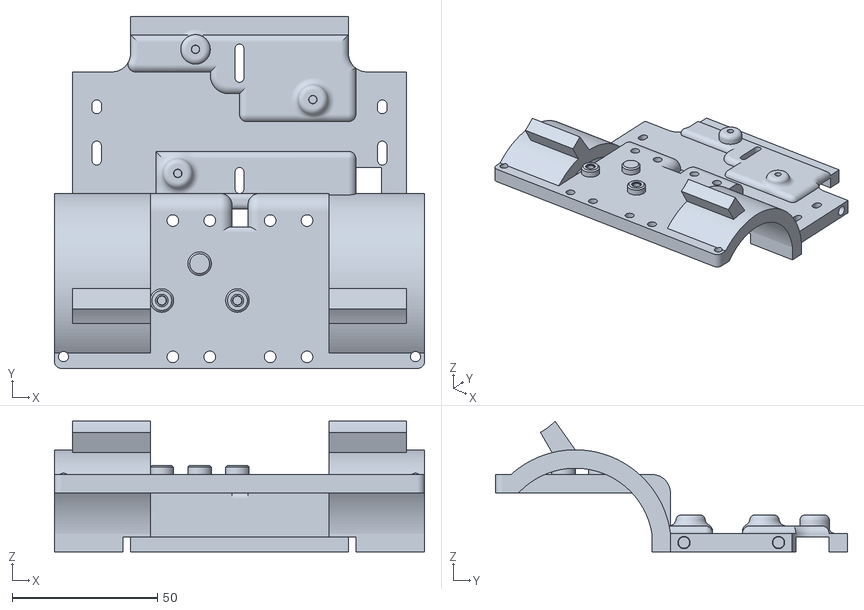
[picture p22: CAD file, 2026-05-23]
hardware/cad/final-chassis.stl
127.5 x 121.1 x 44.9

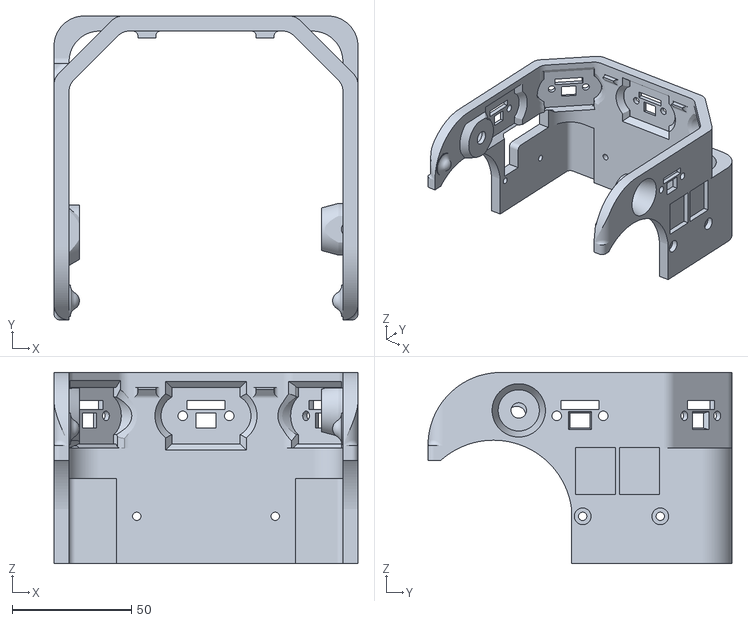
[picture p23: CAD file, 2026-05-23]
hardware/cad/final-enclosure.stl
127.5 x 127.5 x 80.1

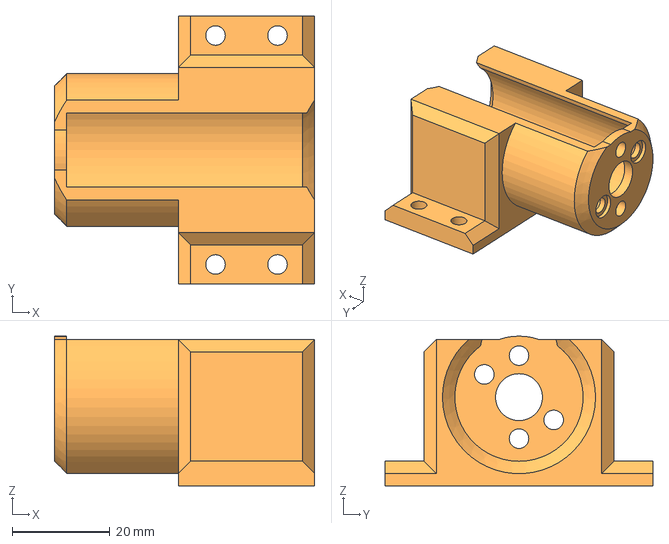
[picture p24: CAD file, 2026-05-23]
hardware/cad/motor-mount-left.step
53.3 x 54.9 x 30.7 mm

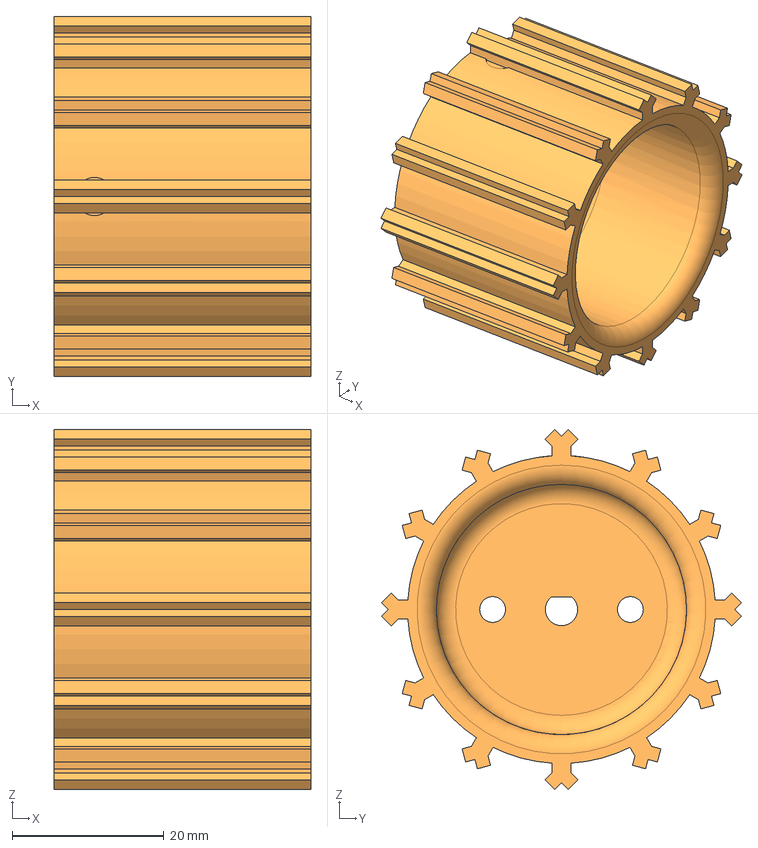
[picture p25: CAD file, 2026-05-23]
hardware/cad/poly-wheel.step
33.9 x 47.5 x 47.5 mm

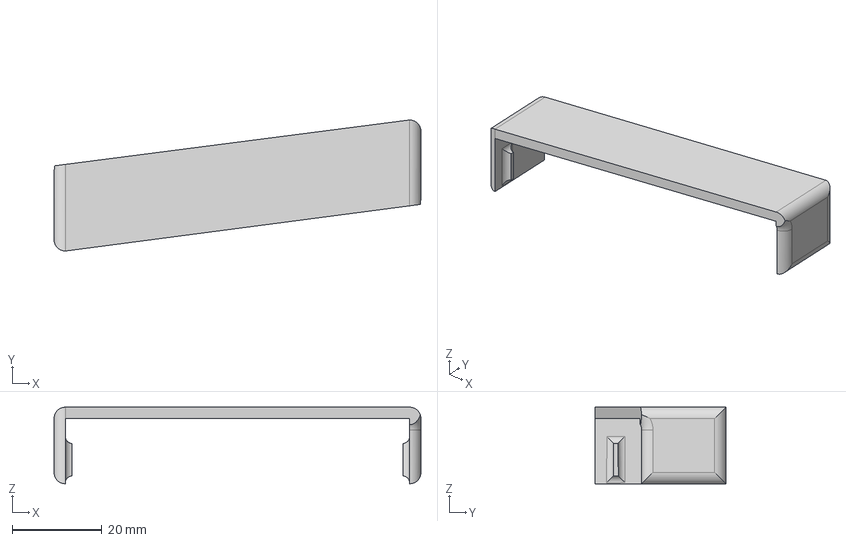
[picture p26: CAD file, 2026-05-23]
hardware/cad/battery-cover.step
81.8 x 29.2 x 17.1 mm

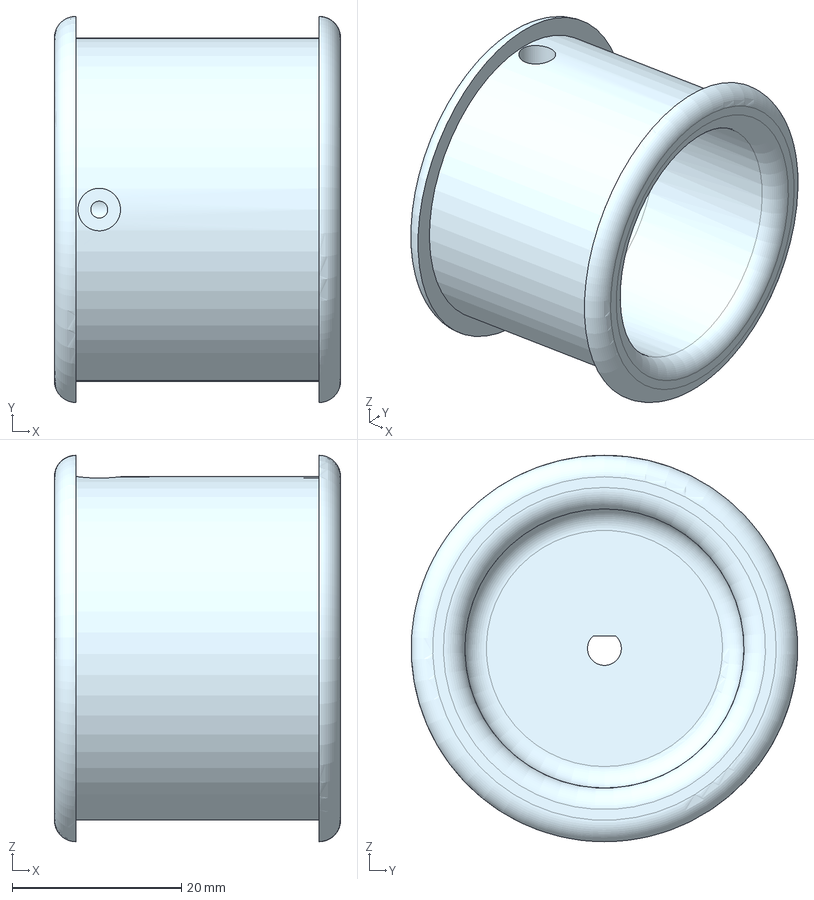
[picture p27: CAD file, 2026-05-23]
hardware/cad/silicone-wheel.step
33.9 x 45.7 x 45.7 mm

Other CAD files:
hardware/cad/motor-mount-right.step

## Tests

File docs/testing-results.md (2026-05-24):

# Testing Results

## Testing Overview

This page summarizes available testing evidence for ZillaBot. The source material includes a documented test plan, D2 final design review results, sensor and navigation testing notes, arena photos, and demonstration videos.

Exact measured values are only included when they are present in the available public records. Several performance values were not formally measured in the public materials, so they are documented as qualitative observations.

## Test Categories

- Functional tests
- Sensor validation
- Navigation behavior tests
- Reliability or repeatability tests
- Competition-style trials

## Documented Test Areas

| Test ID | Objective | Method | Result | Evidence | Notes |
| --- | --- | --- | --- | --- | --- |
| T-01 | Live navigation telemetry stream | Stream and record robot sensor/state data during operation | PASS in source report | Source test report | Source report notes live IR, ToF, IMU, motor, and state data updates |
| T-02 | Boundary detection validation | Test floor-facing sensors against white, black, and brown surfaces | PASS in D2 final design review | [IR reflectivity graphs](../images/testing/fdr-ir-reflectivity-full-trial.png) | IR averages and stability values are listed below |
| T-03 | Object detection validation | Test front time-of-flight sensing against targets and out-of-range conditions | Mixed: out-of-range PASS, within-10-mm accuracy FAIL | [ToF distance graph](../images/testing/fdr-tof-center-distance.png) | ToF response-time sampling passed; one accuracy requirement did not |
| T-04 | Competition/demo behavior | Run robot in arena or demonstration setup | Demonstrated in available video evidence | [Demo videos](media-gallery.md#demo-videos) | Public videos show demonstration activity; formal match outcomes are not documented here |

## Performance Metrics

| Metric | Measured Value | Test Condition | Notes |
| --- | --- | --- | --- |
| Startup delay | 5 seconds | Start button pressed before active match behavior | Product specification describes a five-second countdown before match behavior begins |
| Configured ToF detection range | 1000 mm | Navigation configuration setting test | Listed as PASS in the final design review |
| ToF sampling response | Slowest average sampling frequency: 33.22 Hz; maximum loop-time difference: 3 ms | ToF response-time test | Listed as PASS in the final design review |
| Run consistency | not formally measured in the available public records | Demo and competition-style runs | Available evidence is video-based rather than a formal trial table |

## Sensor and Navigation Test Evidence

### Boundary Detection

The D2 final design review reported the following boundary-sensor analog test averages. The source slide describes the values as averages of 10 readings.

| Surface Condition | Left IR Reading | Right IR Reading | Outcome |
| --- | --- | --- | --- |
| White field/boundary reference | 2040 | 2059.2 | PASS |
| Black surface reference | 58721.2 | 58732.4 | PASS |
| Brown surface reference | 2070.4 | 2062.4 | PASS |

The same review reported a 47.6 Hz IR sampling rate. Stability was reported as 1.6% on white for both sensors, 0.55% on black for the left sensor, and 0.66% on black for the right sensor.

FDR slide images:

| Black-surface reflectivity | White-surface reflectivity | Full-trial reflectivity |
| --- | --- | --- |
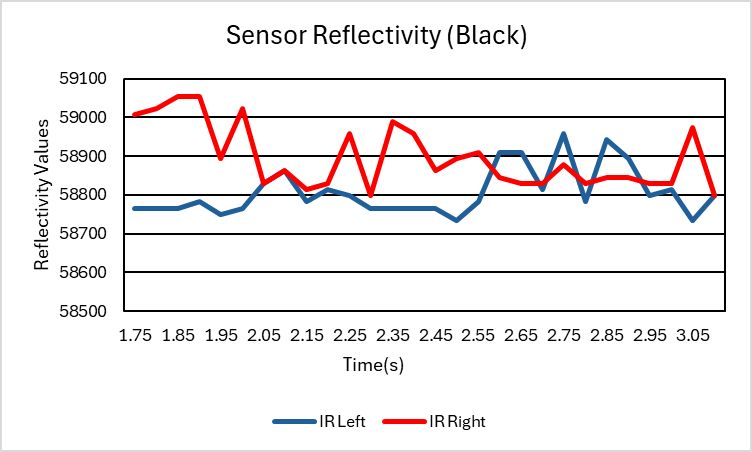
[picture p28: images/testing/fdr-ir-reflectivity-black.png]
Black-surface reflectivity graph
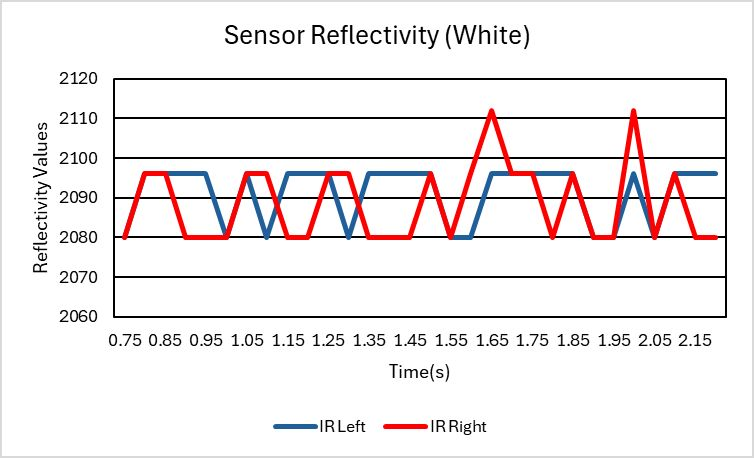
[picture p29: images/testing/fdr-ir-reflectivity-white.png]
White-surface reflectivity graph
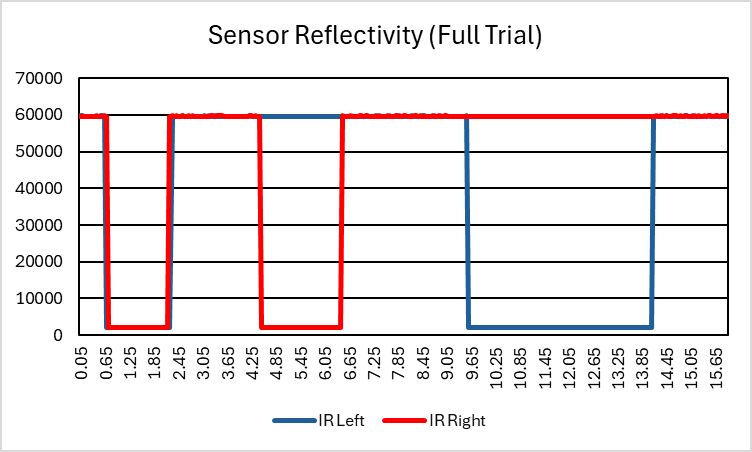
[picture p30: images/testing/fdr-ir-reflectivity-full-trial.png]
Full-trial reflectivity graph
|  |  |  |

### Object Detection

The D2 final design review reported that the VL53L0X ToF sensors returned out-of-range values near 8190: 8190, 8191, 8189, 8190, and 8190. That requirement passed.

The ToF accuracy requirement of reading within 10 mm at each distance did not fully pass. The reported maximum deviations were 40 mm, 12 mm, 12 mm, 17 mm, and 18 mm across the sensor positions. The source notes that testing was performed from 20 cm to 4 cm and that all sensors met the 10 mm target except the right 45-degree sensor.

The ToF response-time test passed. The final design review reported a maximum loop-time difference of 3 ms, maximum consecutive sampling-frequency deviation of 4 Hz, and slowest sampling frequency of 33.22 Hz.

FDR slide images:

| Center | Left 90-degree | Left 45-degree |
| --- | --- | --- |
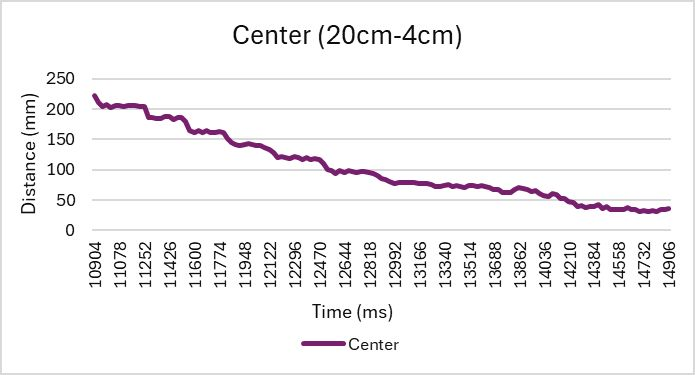
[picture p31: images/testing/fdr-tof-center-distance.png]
Center ToF distance graph
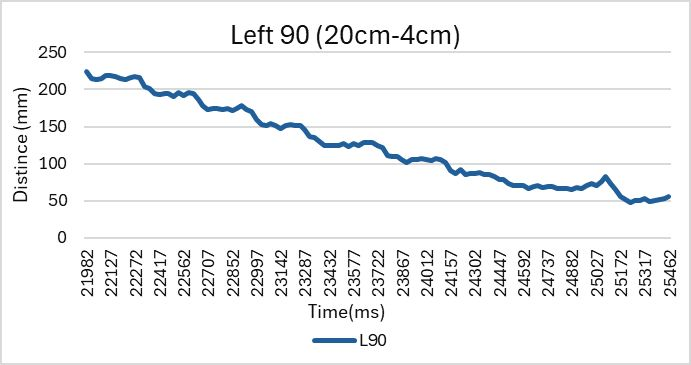
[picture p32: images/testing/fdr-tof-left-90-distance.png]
Left 90-degree ToF distance graph
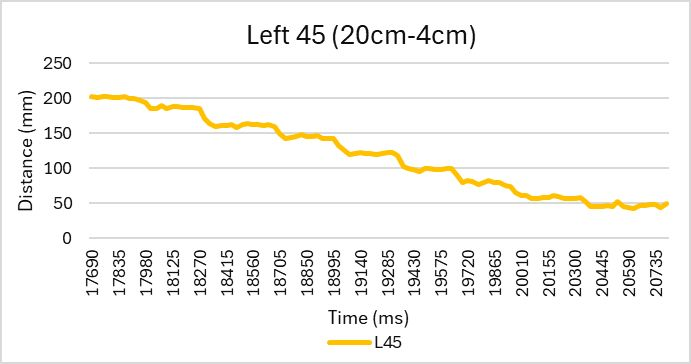
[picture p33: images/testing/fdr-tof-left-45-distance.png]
Left 45-degree ToF distance graph
|  |  |  |

| Right 45-degree | Right 90-degree |
| --- | --- |
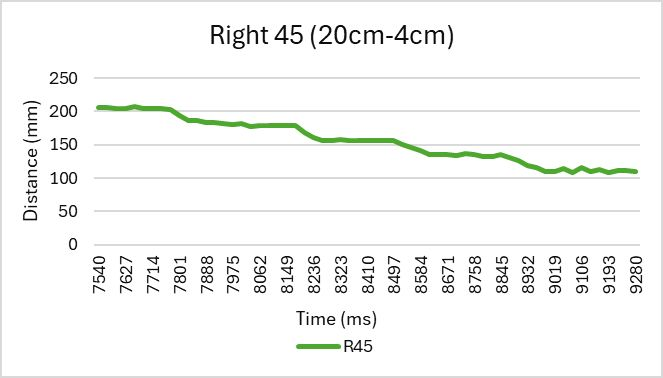
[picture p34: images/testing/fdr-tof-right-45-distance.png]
Right 45-degree ToF distance graph
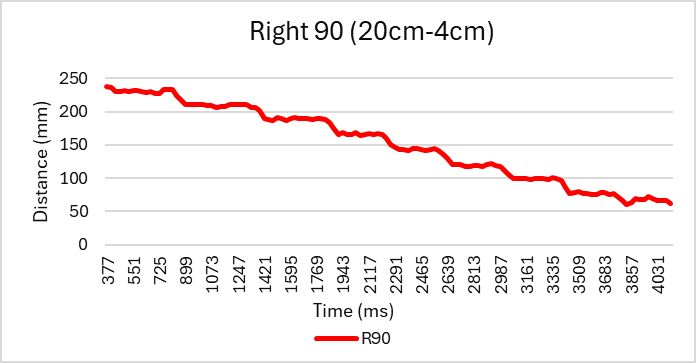
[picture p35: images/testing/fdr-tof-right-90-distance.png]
Right 90-degree ToF distance graph
|  |  |

### Navigation Configuration

| Requirement | Measured or Tuned Result | Outcome |
| --- | --- | --- |
| Boundary thresholds | Left: 38200, Right: 37400 | PASS |
| ToF detection | Range: 1000 mm | PASS |
| Search behavior | Turn: 0.22 s, Burst: 0.15 s, Speed: 0.4 | PASS |
| Avoid behavior | Reverse: -0.6 for 0.6 s, Turn: 0.2 for 0.2 s | PASS |
| Pursuit behavior | Base: 0.6, Attack: 0.8, Align: 0.9 | PASS |
| IMU turning | Filter: 0.10, Turn speed: 0.8 | PASS |

The source review notes that the configuration values were tuned through repeated live robot trials and selected based on ring stability, pursuit behavior, and avoid-state performance. It also notes that higher speeds improved response time but increased self-ring-out risk.

FDR slide images:

| Boundary configuration testing | Weight configuration testing | Live telemetry feed |
| --- | --- | --- |
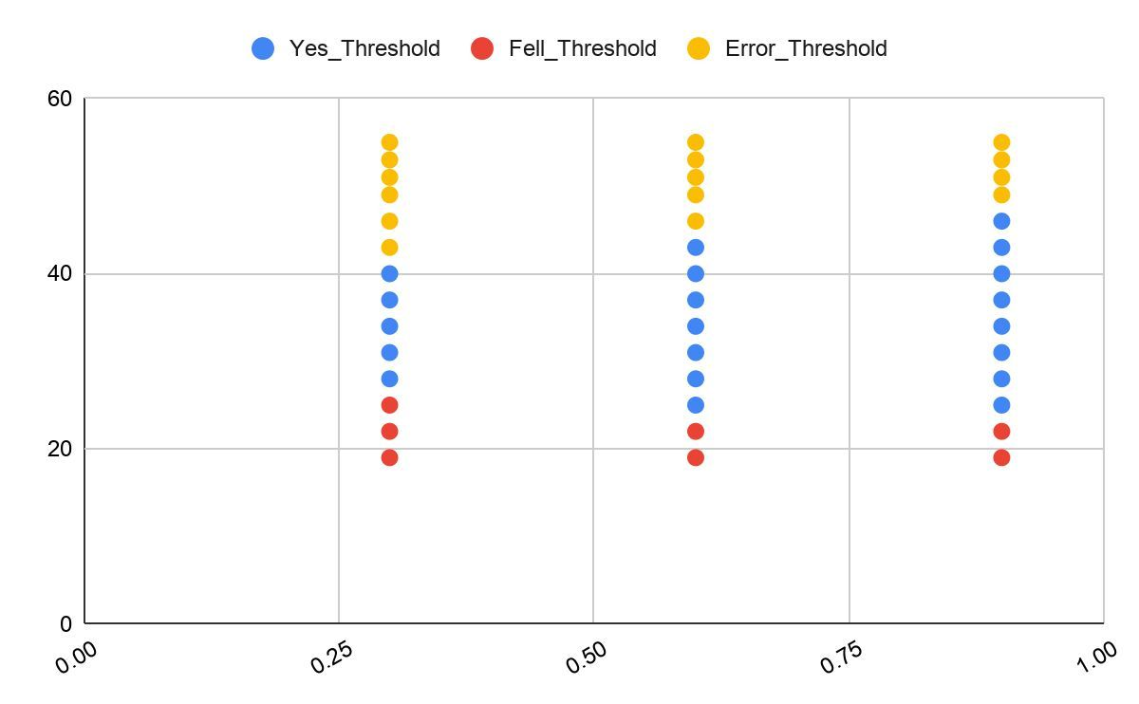
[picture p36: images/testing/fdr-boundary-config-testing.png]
Boundary configuration testing plot
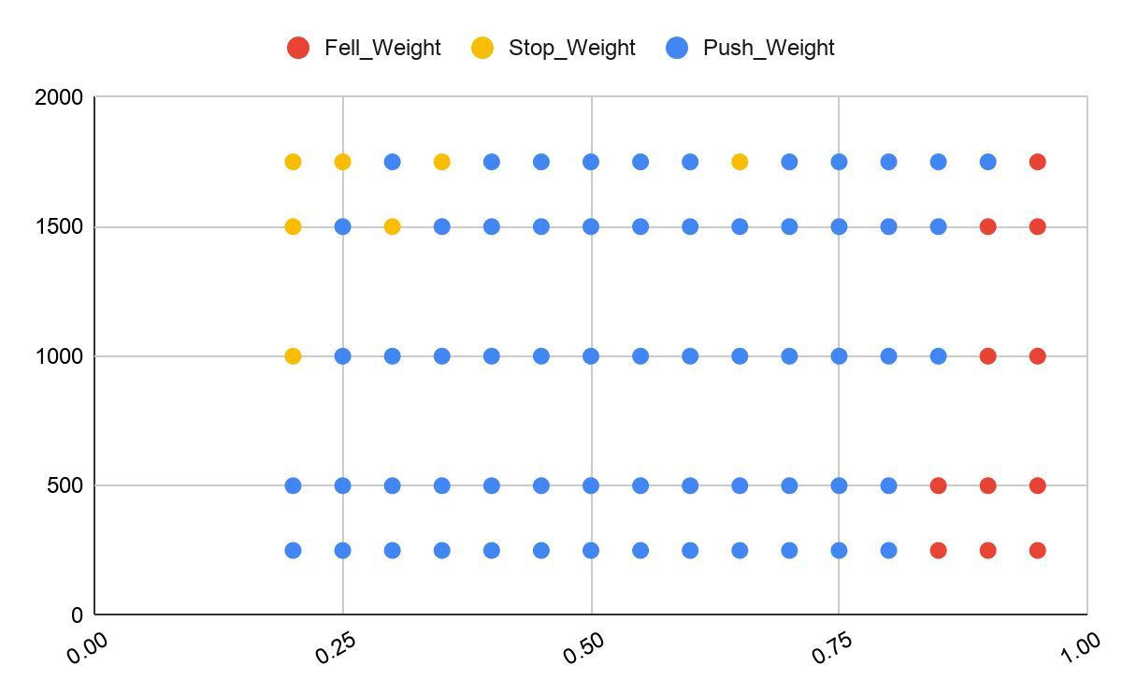
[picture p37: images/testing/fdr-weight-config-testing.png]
Weight configuration testing plot
|  |  | Live telemetry feed screenshot |

### Runtime Estimates

The final design review included estimated runtime values by operating mode.

| Operation Mode | Estimated Runtime |
| --- | --- |
| Standby | 11.59 hours |
| Sumo search | 8.50 hours |
| Sumo push at 1500 g | 4.75 hours |
| Tug at 1000 g | 6.10 hours |

These values are presented as design-review runtime estimates, not independently repeated public endurance trials.

## Traction and Push Testing

The wheel traction test compared the original wheel setup against a revised silicone tread design. The revised tread was tighter-fitting and thicker than the previous tread. The goal of the test was to evaluate whether the robot could maintain traction while pushing increasing loads.

### Push Test Results

| Test Load | Old Wheels Pass Rate | New Silicone Tread Pass Rate |
| --- | --- | --- |
| 1500 g | 98% | 100% |
| 1750 g | 54% | 100% |
| 2250 g | 1% | 100% |
| 2500 g | Failed / did not pass | 100% |
| 3000 g | Not tested in available old-wheel data | 100% |

### Test Context and Limitations

- Old wheel results were based on about 20 tests per weight.
- New silicone tread results were based on about 3 tests per weight.
- The 100% pass rates for the new tread are promising, but they are based on a smaller sample size than the old-wheel data.
- The tighter and thicker silicone tread greatly improved traction during push testing.
- The added traction also made the robot faster and more aggressive during attacks, which meant the navigation thresholds needed retuning because the robot could drive out of the arena during attack behavior.

## Test Evidence

Current visual evidence:

- [Arena test setup](../images/testing/build-test-setup.jpg)
- [FDR arena test photo](../images/testing/fdr-arena-test-photo.png)
- [April 13 demo run](../videos/2026-04-13-demo-run.mp4)
- [May 10 competition run](../videos/2026-05-10-competition-run.mp4)
- [Short demonstration clip](../videos/short-demo-clip.mp4)

## Observations

- The project source materials describe telemetry as useful for debugging live sensor and state behavior.
- Boundary detection and object detection were treated as separate validation areas during the test planning process, with D2 final design review values available for both.
- Demonstration videos provide public evidence of the robot operating, but they do not replace a controlled test table with repeated trials.
- The traction/push test provides useful engineering evidence, while broader match repeatability statistics are still not formally published in this repository.

## Summary

The available public records support that ZillaBot was tested through subsystem checks, telemetry-assisted debugging, sensor validation, navigation configuration tuning, traction/push testing, and demonstration runs. The traction data shows a clear improvement from the revised silicone tread, while the smaller sample size for the new wheels should be considered when interpreting the 100% pass rates. The D2 test evidence also shows honest limitations: ToF out-of-range and response-time behavior passed, but one ToF accuracy requirement did not fully pass.

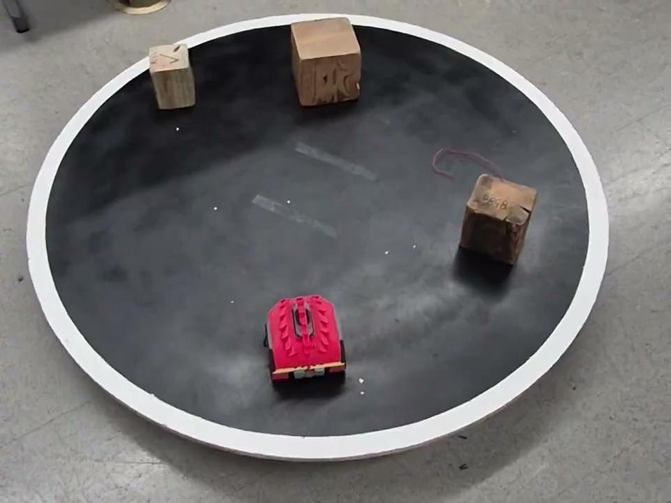
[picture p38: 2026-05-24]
images/testing/fdr-arena-test-photo.png

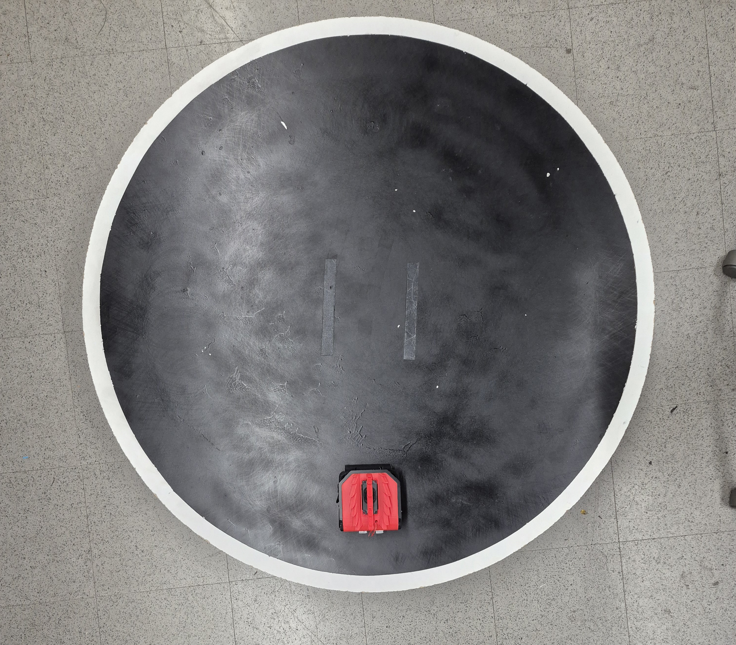
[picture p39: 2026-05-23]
images/testing/build-test-setup.jpg

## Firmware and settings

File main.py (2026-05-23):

# =========================
# main.py
# =========================

import gc
import time
from machine import Pin

try:
    import _thread
except Exception:
    _thread = None

import core0_motor as motors
import core1_navigation as nav

try:
    import dfplayer
except Exception:
    dfplayer = None

from config import (
    MODE_1_SUMO,
    MODE_2_TUG,
    ENABLE_SENSOR_FILE_LOGGING,
    TRACK_COUNTDOWN_ROAR,
    SUMO_SELECTED_TRACK,
    TUG_SELECTED_TRACK,
)


MODE_PROGRAM = 0
DEFAULT_TOF_COUNT = 5
BUILD_TAG = "2026-05-02-main-rebuild-1"

DFPLAYER_VOLUME = 20

DEBOUNCE_S = 0.20
SW_DEBOUNCE_MS = 50
DELAY_ON_MS = 200
DELAY_OFF_MS = 800
SENSOR_SETTLE_MS = 500
SENSOR_RECHECK_MS = 250
SENSOR_LIVE_TIMEOUT_MS = 500


# ======================================================
# Sensor core bring-up
# ======================================================

sensor_core_available = False

try:
    import core0_sensors as sensors

    set_sensor_power = getattr(sensors, "set_sensor_power", lambda enabled: None)
    request_imu_calibration = getattr(sensors, "request_imu_calibration", lambda: None)
    start_file_logging = getattr(sensors, "start_file_logging", lambda *args, **kwargs: False)
    stop_file_logging = getattr(sensors, "stop_file_logging", lambda: None)

    imu_state = getattr(sensors, "imu_state")
    boundary_state = getattr(sensors, "boundary_state")
    tof_state = getattr(sensors, "tof_state")
    sensor_runtime_state = getattr(
        sensors,
        "sensor_runtime_state",
        {"enabled": False, "last_loop_ms": 0},
    )

    started = False
    start_sensor_core = getattr(sensors, "start_sensor_core", None)
    if callable(start_sensor_core):
        start_sensor_core()
        started = True
    else:
        sensor_thread = getattr(sensors, "sensor_thread", None)
        if callable(sensor_thread) and _thread is not None:
            if not bool(getattr(sensors, "_started", False)):
                setattr(sensors, "_started", True)
                _thread.start_new_thread(sensor_thread, ())
            started = True

    sensor_core_available = started
    if started:
        print("[MAIN] Sensor core started")
    else:
        print("[MAIN] Sensor core start helper unavailable")

except Exception as e:
    print("[MAIN] Sensor core failed to start:", e)

    def set_sensor_power(enabled):
        return None

    def request_imu_calibration():
        return None

    def start_file_logging(*args, **kwargs):
        return False

    def stop_file_logging():
        return None

    imu_state = {"heading": 0.0, "ok": False}
    boundary_state = {
        "left": 0,
        "right": 0,
        "left_sumo": False,
        "right_sumo": False,
        "left_tug": False,
        "right_tug": False,
        "left_blue": False,
        "right_blue": False,
        "left_black": False,
        "right_black": False,
    }
    tof_state = {
        "ok": False,
        "mm": [0] * DEFAULT_TOF_COUNT,
        "min": 0,
    }
    sensor_runtime_state = {"enabled": False, "last_loop_ms": 0}


# ======================================================
# Pins
# ======================================================

def init_control_pins():
    global btn_start, sw_sumo, sw_tug, led

    btn_start = Pin(0, Pin.IN, Pin.PULL_DOWN)
    sw_sumo = Pin(1, Pin.IN, Pin.PULL_UP)
    sw_tug = Pin(2, Pin.IN, Pin.PULL_UP)

    try:
        led = Pin("LED", Pin.OUT)
    except Exception:
        led = Pin(25, Pin.OUT)


init_control_pins()


# ======================================================
# State
# ======================================================

sensor_mode_enabled = False
sensor_ready = False
sensor_ready_at_ms = 0
sensor_wait_reason = ""

audio_enabled = False
audio_ready = False

_last_sw_raw = None
_last_sw_change_ms = time.ticks_ms()
last_start = 0
last_start_ms = 0


# ======================================================
# Helpers
# ======================================================

def _mode_name(mode):
    if mode == MODE_PROGRAM:
        return "PROGRAM"
    if mode == MODE_1_SUMO:
        return "SUMO"
    if mode == MODE_2_TUG:
        return "TUG"
    return str(mode)


def decode_switch():
    s = sw_sumo.value()
    t = sw_tug.value()

    if s == 0 and t == 1:
        return MODE_1_SUMO
    if s == 1 and t == 0:
        return MODE_2_TUG
    if s == 1 and t == 1:
        return MODE_PROGRAM
    return "INVALID"


def read_switch_debounced():
    global _last_sw_raw, _last_sw_change_ms

    raw = decode_switch()
    now = time.ticks_ms()

    if _last_sw_raw is None:
        _last_sw_raw = raw
        _last_sw_change_ms = now
        return raw

    if raw != _last_sw_raw:
        _last_sw_raw = raw
        _last_sw_change_ms = now
        return None

    if time.ticks_diff(now, _last_sw_change_ms) >= SW_DEBOUNCE_MS:
        return raw

    return None


def setup_audio():
    global audio_enabled, audio_ready

    if dfplayer is None:
        audio_enabled = False
        audio_ready = False
        print("[AUDIO] DFPlayer import unavailable")
        return False

    audio_enabled = True
    audio_ready = False
    print("[AUDIO] DFPlayer available")
    return True


def warm_audio():
    global audio_ready

    if not audio_enabled or dfplayer is None:
        return False

    if audio_ready:
        return True

    try:
        dfplayer.init(volume=DFPLAYER_VOLUME)
        audio_ready = True
        print("[AUDIO] DFPlayer warmed at volume", DFPLAYER_VOLUME)
        return True
    except Exception as e:
        print("[AUDIO] warm failed:", repr(e))
        audio_ready = False
        return False


def apply_audio_volume():
    if not audio_enabled or dfplayer is None:
        return False

    try:
        if hasattr(dfplayer, "set_volume"):
            dfplayer.set_volume(DFPLAYER_VOLUME)
        return True
    except Exception as e:
        print("[AUDIO] volume set failed:", repr(e))
        return False


def start_countdown_audio():
    if not audio_enabled or dfplayer is None:
        return False

    try:
        if not warm_audio():
            return False
        apply_audio_volume()
        dfplayer.play(int(TRACK_COUNTDOWN_ROAR))
        print("[AUDIO] playing: COUNTDOWN at volume", DFPLAYER_VOLUME)
        return True
    except Exception as e:
        print("[AUDIO] countdown start failed:", repr(e))
        return False


def _match_track_for_mode(mode):
    if mode == MODE_1_SUMO:
        return SUMO_SELECTED_TRACK, "SUMO"

    if mode == MODE_2_TUG:
        return TUG_SELECTED_TRACK, "TUG"

    return 0, ""


def start_match_audio(mode):
    if not audio_enabled or dfplayer is None:
        return False

    raw_track, label = _match_track_for_mode(mode)
    try:
        track = int(raw_track)
    except Exception:
        track = 0

    if track <= 0:
        print("[AUDIO]", label or "MATCH", "track disabled/invalid:", raw_track)
        return False

    try:
        if not warm_audio():
            return False
        apply_audio_volume()
        dfplayer.play(track)
        print(
            "[AUDIO] playing:",
            label or "MATCH",
            "track",
            track,
            "at volume",
            DFPLAYER_VOLUME,
        )
        return True
    except Exception as e:
        print("[AUDIO] match start failed:", repr(e))
        return False


def stop_audio(label=""):
    if not audio_enabled or dfplayer is None:
        return False

    try:
        dfplayer.stop()
        if label:
            print("[AUDIO] stopped:", label)
        return True
    except Exception as e:
        print("[AUDIO] stop failed:", repr(e))
        return False


def sensor_status(current_mode, now_ms=None):
    if current_mode == MODE_PROGRAM:
        return True, ""

    if not sensor_core_available:
        return False, "sensor core unavailable"

    if now_ms is None:
        now_ms = time.ticks_ms()

    last_loop_ms = int(sensor_runtime_state.get("last_loop_ms", 0) or 0)
    if last_loop_ms > 0 and time.ticks_diff(now_ms, last_loop_ms) > SENSOR_LIVE_TIMEOUT_MS:
        return False, "sensor thread stale"

    left_raw = int(boundary_state.get("left", 0))
    right_raw = int(boundary_state.get("right", 0))
    if left_raw <= 0 and right_raw <= 0:
        return False, "IR sensors not live"

    if not bool(imu_state.get("ok", False)):
        return False, "IMU not ready"

    if current_mode == MODE_1_SUMO and not bool(tof_state.get("ok", False)):
        return False, "ToF not ready"

    return True, ""


def sync_sensor_mode(current_mode):
    global sensor_mode_enabled, sensor_ready, sensor_ready_at_ms, sensor_wait_reason

    sensors_on = current_mode in (MODE_1_SUMO, MODE_2_TUG)
    if sensors_on == sensor_mode_enabled:
        return

    sensor_mode_enabled = sensors_on
    set_sensor_power(sensors_on)
    sensor_ready = False
    sensor_wait_reason = ""

    if sensors_on:
        sensor_ready_at_ms = time.ticks_add(time.ticks_ms(), SENSOR_SETTLE_MS)
    else:
        sensor_ready_at_ms = 0


def start_countdown_5s(mode):
    start_countdown_audio()

    for i in range(5, 0, -1):
        print("[MAIN] Starting in", i, "...")
        led.value(1)
        time.sleep(DELAY_ON_MS / 1000)
        led.value(0)
        time.sleep(DELAY_OFF_MS / 1000)

    stop_audio("COUNTDOWN_DONE")
    start_match_audio(mode)


def led_tick(current_mode):
    now = time.ticks_ms()
    phase = (now // 200) % 2

    if current_mode == MODE_PROGRAM:
        led.value(phase)
        return

    if not sensor_ready:
        led.value((now // 600) % 2)
        return

    if current_mode == MODE_1_SUMO:
        led.value(1 if phase else 0)
        return

    if current_mode == MODE_2_TUG:
        led.value(1 if ((now // 100) % 4) < 2 else 0)
        return

    led.value(0)


# ======================================================
# Setup
# ======================================================

print("=== ZillaBot Mode Codes ===")
print("[MAIN] BUILD:", BUILD_TAG)
print("MODE 0 PROGRAM")
print("MODE 1 SUMO")
print("MODE 2 TUG")
print("GP0 START -> required 5s visible countdown then run")

motors.stop()
setup_audio()
warm_audio()
init_control_pins()

mode = decode_switch()
if mode == "INVALID":
    mode = MODE_PROGRAM

sync_sensor_mode(mode)
print("[MAIN] Initial mode:", _mode_name(mode))


# ======================================================
# Main loop
# ======================================================

while True:
    now = time.ticks_ms()

    if sensor_mode_enabled:
        ready_now, wait_reason = sensor_status(mode, now)

        if sensor_ready and not ready_now:
            sensor_ready = False
            sensor_ready_at_ms = time.ticks_add(now, SENSOR_RECHECK_MS)
            if wait_reason and wait_reason != sensor_wait_reason:
                sensor_wait_reason = wait_reason
                print("[MAIN] Sensors lost / start blocked:", wait_reason)

        elif (not sensor_ready) and time.ticks_diff(now, sensor_ready_at_ms) >= 0:
            if ready_now:
                sensor_ready = True
                sensor_wait_reason = ""
                print("[MAIN] Sensors ready / start allowed")
            else:
                sensor_ready_at_ms = time.ticks_add(now, SENSOR_RECHECK_MS)
                if wait_reason and wait_reason != sensor_wait_reason:
                    sensor_wait_reason = wait_reason
                    print("[MAIN] Waiting on sensors:", wait_reason)
    else:
        sensor_ready = False
        sensor_wait_reason = ""

    sel = read_switch_debounced()
    if sel == "INVALID":
        pass
    elif sel in (MODE_PROGRAM, MODE_1_SUMO, MODE_2_TUG) and sel != mode:
        mode = sel
        sync_sensor_mode(mode)
        print("[MAIN] Mode changed to:", _mode_name(mode))
        if mode in (MODE_1_SUMO, MODE_2_TUG):
            warm_audio()

    s = btn_start.value()
    if s == 1 and last_start == 0:
        now_ms = time.ticks_ms()

        if time.ticks_diff(now_ms, last_start_ms) > int(DEBOUNCE_S * 1000):
            if mode == MODE_PROGRAM:
                print("[MAIN] START ignored (PROGRAM)")
            elif not sensor_ready:
                if sensor_wait_reason:
                    print("[MAIN] START ignored (" + sensor_wait_reason + ")")
                else:
                    print("[MAIN] START ignored (sensors not ready)")
            else:
                print("[MAIN] START pressed in mode:", _mode_name(mode))

                try:
                    request_imu_calibration()
                except Exception as e:
                    print("[MAIN] IMU calibration request failed:", repr(e))

                start_countdown_5s(mode)

                nav.set_mode(mode)
                gc.collect()

                if ENABLE_SENSOR_FILE_LOGGING:
                    start_file_logging("sensor_log.csv", period_ms=100)

                try:
                    nav.run_selected_mode()
                finally:
                    if ENABLE_SENSOR_FILE_LOGGING:
                        stop_file_logging()

                motors.stop()

            last_start_ms = now_ms

    last_start = s
    led_tick(mode)
    time.sleep(0.01)

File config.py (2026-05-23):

# ================================================================
# config.py
# CONFIG — ZillaBot V3
# New board + new pin layout
# ================================================================

# -------------------------
# Modes
# -------------------------
MODE_1_SUMO = 1
MODE_2_TUG  = 2

# -------------------------
# States
# -------------------------
STATE_SEARCH = 0
STATE_AVOID  = 1
STATE_SCAN   = 2
STATE_PURSUE = 3
STATE_TUG    = 4

# -------------------------
# Audio tracks
# -------------------------
# 1 = roar
# 2 = sumo1_welcome-to-the-jungle
# 3 = sumo2_kung-fu-fighting
# 4 = sumo3_iron-man
# 5 = blockpull_gonna-fly-now
# 6 = tug1_immigrant-song
# 7 = tug2_seven-nation-army
TRACK_COUNTDOWN_ROAR = 1
SUMO_SELECTED_TRACK = 2
TUG_SELECTED_TRACK = 6
MODE_2_SELECTED_TRACK = TUG_SELECTED_TRACK  # compatibility alias

# -------------------------
# Motor pins
# -------------------------
LEFT_MOTOR_PWM = 8
LEFT_MOTOR_IN1 = 7
LEFT_MOTOR_IN2 = 6

RIGHT_MOTOR_PWM = 3
RIGHT_MOTOR_IN1 = 4
RIGHT_MOTOR_IN2 = 5

# -------------------------
# Runtime feature flags
# -------------------------
# Disable sensor CSV logging by default so flash writes never slow
# the sensor thread during a match.
ENABLE_SENSOR_FILE_LOGGING = False

# Disable Wi-Fi / UDP telemetry by default so data collection never
# steals time from the control loop.
ENABLE_TELEMETRY = False

# Keep navigation hot-loop prints off by default. Serial output can
# block on MicroPython and add jitter during a match.
ENABLE_NAV_DEBUG_PRINTS = False

# Poll the ToF array more slowly than the 100 Hz sensor loop and reuse
# the previous reading between polls.
TOF_POLL_MS = 40

# If telemetry is re-enabled later, keep run telemetry light enough to
# avoid churn in the motion loop.
TELEMETRY_RUN_MS = 75

# -------------------------
# IR boundary sensors
# -------------------------
IR_LEFT_ADC_PIN  = 27
IR_RIGHT_ADC_PIN = 26

# SUMO thresholds
# Measured roughly:
#   mat  ~35k
#   blue ~39k–40k
# In SUMO, blue tape means edge hit.
SUMO_BLUE_L_THRESHOLD = 38200
SUMO_BLUE_R_THRESHOLD = 37400

# Legacy / compatibility
BOUNDARY_BLUE_THRESHOLD = 38500

# SUMO wander timing
SUMO_SEARCH_TURN_S  = 0.22
SUMO_SEARCH_BURST_S = 0.15

# TUG thresholds
# Measured roughly:
#   mat   ~35k
#   blue  ~39k–40k
#   black ~54k–56k
TUG_BLUE_L_THRESHOLD = 30000
TUG_BLUE_R_THRESHOLD = 30000
TUG_BLACK_THRESHOLD = 52000

# Legacy / unused
BOUNDARY_BLACK_THRESHOLD = 55000
BOUNDARY_BROWN_THRESHOLD = 34500

# -------------------------
# ToF
# -------------------------
TOF_SDA = 16
TOF_SCL = 17

# Keep the logical slot order fixed as:
# [L90, L45, C, R45, R90]
#
# The outer slots stay listed so their XSHUT pins can still be driven low
# when those sensors are plugged in but not used on the 3-sensor bot.
# Set the first/last entries to True to re-enable L90 and R90 later.
TOF_NAMES     = ["L90", "L45", "C", "R45", "R90"]
TOF_XSHUT     = [18, 19, 20, 21, 22]
TOF_ADDRESSES = [0x31, 0x32, 0x33, 0x34, 0x35]
TOF_ENABLED   = [True, True, True, True, True]

TOF_DETECT_RANGE = 1000  # mm

# -------------------------
# IMU (LSM6DS3)
# -------------------------
IMU_SDA = 14
IMU_SCL = 15

IMU_HEADING_FILTER = 0.10
IMU_TURN_SPEED     = 0.8   # slightly stronger for bigger avoid turns

# -------------------------
# SUMO navigation tuning
# -------------------------
SEARCH_SPEED        = 0.4
AVOID_REVERSE_SPEED = -0.6
AVOID_TURN_SPEED    = 0.2
AVOID_REVERSE_TIME  = 0.6
AVOID_TURN_TIME     = 0.2

# Centered target attack profile:
# far target -> HUNT_BASE_SPEED
# mid target -> ramp up toward HUNT_ATTACK_SPEED
# close stable target -> short HUNT_BURST_SPEED launch
HUNT_BASE_SPEED       = 0.6
HUNT_ATTACK_SPEED     = 0.9
HUNT_ALIGN_SPEED      = 0.75
HUNT_BURST_SPEED      = 1.0
HUNT_ATTACK_RAMP_MM   = 320
HUNT_BURST_DIST_MM    = 160
HUNT_CENTER_LOCK_MS   = 80
HUNT_BURST_MS         = 140
SUMO_EDGE_CONFIRM_MS  = 12

# Face-lock breakout:
# if the center target stays close and distance barely changes,
# do a short forward-biased shoulder break to slip onto a 45 sensor.
SUMO_STALEMATE_DIST_MM          = 170
SUMO_STALEMATE_DELTA_MM         = 18
SUMO_STALEMATE_MS               = 320
SUMO_SHOULDER_BREAK_INNER_SPEED = 0.55
SUMO_SHOULDER_BREAK_OUTER_SPEED = 0.92
SUMO_SHOULDER_BREAK_MS          = 180
SUMO_SHOULDER_BREAK_MAX_DEG     = 18.0
SUMO_SHOULDER_BIAS_MM           = 35

# Legacy / older motion values
TUG_REVERSE_SPEED = -0.70
TURN_SPEED        = 0.55
PATTERN_SPEED     = 0.60

# -------------------------
# TUG mode tuning
# -------------------------

# Legacy / not used for finish anymore
TUG_TARGET_BLUE_LINES = 18

# Forward drive + heading correction
TUG_BASE_SPEED     = 0.65
TUG_HEADING_KP     = 0.020
TUG_MAX_CORRECTION = 0.25
TUG_HEADING_DEADBAND_DEG = 2.0
TUG_CORRECTION_SMOOTHING = 0.25
TUG_BOTH_DARK_CONFIRM_MS = 200
TUG_ONE_SIDE_CONFIRM_MS  = 300
TUG_ONE_SIDE_RECOVER     = True
TUG_EDGE_RECOVERY_BIAS   = 0.18
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

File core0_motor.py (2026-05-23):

from machine import Pin, PWM
from config import (
    LEFT_MOTOR_PWM,
    LEFT_MOTOR_IN1,
    LEFT_MOTOR_IN2,
    RIGHT_MOTOR_PWM,
    RIGHT_MOTOR_IN1,
    RIGHT_MOTOR_IN2,
)

# ======================================================
# MOTOR DRIVER: TB6612FNG
# ======================================================

# Calibration
MIN_DUTY = 0.22
DEADBAND = 0.05

LEFT_GAIN = 1.00
RIGHT_GAIN = 1.00

# ======================================================
# Telemetry-visible motor state
# Values are normalized command values in range -1.0 .. +1.0
# ======================================================

motor_state = {
    "left_cmd": 0.0,
    "right_cmd": 0.0,
    "move_cmd": 0.0,
    "active": False,
}

# ======================================================
# PWM setup
# ======================================================

pwm_left = PWM(Pin(LEFT_MOTOR_PWM))
pwm_right = PWM(Pin(RIGHT_MOTOR_PWM))

pwm_left.freq(20000)
pwm_right.freq(20000)

# ======================================================
# Direction pins
# ======================================================

ain1 = Pin(LEFT_MOTOR_IN1, Pin.OUT)
ain2 = Pin(LEFT_MOTOR_IN2, Pin.OUT)
bin1 = Pin(RIGHT_MOTOR_IN1, Pin.OUT)
bin2 = Pin(RIGHT_MOTOR_IN2, Pin.OUT)

# Safety off on import
ain1.value(0)
ain2.value(0)
bin1.value(0)
bin2.value(0)

pwm_left.duty_u16(0)
pwm_right.duty_u16(0)

# ======================================================
# Helpers
# ======================================================

def _clamp_cmd(x):
    x = float(x)
    if x > 1.0:
        return 1.0
    if x < -1.0:
        return -1.0
    return x


def _update_motor_state(left_cmd, right_cmd):
    left_cmd = _clamp_cmd(left_cmd)
    right_cmd = _clamp_cmd(right_cmd)

    motor_state["left_cmd"] = left_cmd
    motor_state["right_cmd"] = right_cmd
    motor_state["move_cmd"] = (left_cmd + right_cmd) / 2.0
    motor_state["active"] = (abs(left_cmd) > 0.001 or abs(right_cmd) > 0.001)


def _set_speed(pwm, speed):
    speed = float(speed)
    speed = max(0.0, min(1.0, speed))

    if speed < DEADBAND:
        speed = 0.0
    elif speed < MIN_DUTY:
        speed = MIN_DUTY

    pwm.duty_u16(int(65535 * speed))


# ======================================================
# Basic drive functions
# ======================================================

def stop():
    _set_speed(pwm_left, 0)
    _set_speed(pwm_right, 0)

    ain1.value(0)
    ain2.value(0)
    bin1.value(0)
    bin2.value(0)

    _update_motor_state(0.0, 0.0)


def forward(speed):
    speed = _clamp_cmd(speed)

    ain1.value(1)
    ain2.value(0)
    bin1.value(1)
    bin2.value(0)

    _set_speed(pwm_left, speed * LEFT_GAIN)
    _set_speed(pwm_right, speed * RIGHT_GAIN)

    _update_motor_state(speed, speed)


def reverse(speed):
    speed = abs(_clamp_cmd(speed))

    ain1.value(0)
    ain2.value(1)
    bin1.value(0)
    bin2.value(1)

    _set_speed(pwm_left, speed * LEFT_GAIN)
    _set_speed(pwm_right, speed * RIGHT_GAIN)

    _update_motor_state(-speed, -speed)


def turn_left(speed):
    speed = abs(_clamp_cmd(speed))

    ain1.value(0)
    ain2.value(1)
    bin1.value(1)
    bin2.value(0)

    _set_speed(pwm_left, speed * LEFT_GAIN)
    _set_speed(pwm_right, speed * RIGHT_GAIN)

    _update_motor_state(-speed, speed)


def turn_right(speed):
    speed = abs(_clamp_cmd(speed))

    ain1.value(1)
    ain2.value(0)
    bin1.value(0)
    bin2.value(1)

    _set_speed(pwm_left, speed * LEFT_GAIN)
    _set_speed(pwm_right, speed * RIGHT_GAIN)

    _update_motor_state(speed, -speed)


# ======================================================
# Independent wheel control
# left_speed, right_speed in range -1.0 .. +1.0
# ======================================================

def set_wheels(left_speed, right_speed):
    left_speed = _clamp_cmd(left_speed)
    right_speed = _clamp_cmd(right_speed)

    # LEFT
    if left_speed >= 0:
        ain1.value(1)
        ain2.value(0)
        _set_speed(pwm_left, left_speed * LEFT_GAIN)
    else:
        ain1.value(0)
        ain2.value(1)
        _set_speed(pwm_left, -left_speed * LEFT_GAIN)

    # RIGHT
    if right_speed >= 0:
        bin1.value(1)
        bin2.value(0)
        _set_speed(pwm_right, right_speed * RIGHT_GAIN)
    else:
        bin1.value(0)
        bin2.value(1)
        _set_speed(pwm_right, -right_speed * RIGHT_GAIN)

    _update_motor_state(left_speed, right_speed)

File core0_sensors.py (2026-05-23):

# ======================================================
# core0_sensors.py
# ======================================================

import time
import _thread
import struct
from machine import ADC, I2C, Pin

import vl53l0x

from config import (
    IR_LEFT_ADC_PIN,
    IR_RIGHT_ADC_PIN,
    BOUNDARY_BLUE_THRESHOLD,
    ENABLE_SENSOR_FILE_LOGGING,
    TOF_POLL_MS,

    TUG_BLUE_L_THRESHOLD,
    TUG_BLUE_R_THRESHOLD,
    TUG_BLACK_THRESHOLD,
    TUG_LINE_COOLDOWN_MS,

    IMU_SDA,
    IMU_SCL,
    IMU_HEADING_FILTER,

    TOF_SDA,
    TOF_SCL,
    TOF_NAMES,
    TOF_XSHUT,
    TOF_ADDRESSES,
    TOF_ENABLED,
)

# ======================================================
# Shared state
# ======================================================

boundary_state = {
    "left": 0,
    "right": 0,

    "left_sumo": False,
    "right_sumo": False,

    "left_tug": False,
    "right_tug": False,

    "left_blue": False,
    "right_blue": False,
    "left_black": False,
    "right_black": False,

    "tug_blue_count": 0,
    "tug_last_blue_ms": 0,
}

imu_state = {
    "heading": 0.0,
    "gx_dps": 0.0,
    "gy_dps": 0.0,
    "gz_dps": 0.0,
    "turn_rate_dps": 0.0,
    "bias_x_dps": 0.0,
    "bias_y_dps": 0.0,
    "bias_z_dps": 0.0,
    "ok": False,
    "calibrate_requested": False,
    "calibrating": False,
}

tof_state = {
    "ok": False,
    "mm": [0] * len(TOF_NAMES),
    "min": 0,
}

sensor_runtime_state = {
    "enabled": False,
    "last_loop_ms": 0,
}

_started = False
_sensors_enabled = False

# ======================================================
# File logging state
# ======================================================

_log_enabled = False
_log_fp = None
_log_period_ms = 100
_log_last_ms = 0
_log_flush_every = 10
_log_rows_since_flush = 0

# ======================================================
# Retry / calibration timing
# ======================================================

IMU_RETRY_MS = 2000
TOF_RETRY_MS = 2000

IMU_CAL_SAMPLES = 120
IMU_CAL_DELAY_MS = 5

IMU_GYRO_DEADBAND_DPS = 0.5

# Pick which gyro axis represents bot turning.
# Try "z" first if the board is flat.
# If heading stays stuck, switch to "x" or "y".
HEADING_AXIS = "z"

# ======================================================
# Helpers
# ======================================================

def _angle_wrap_360(x):
    x %= 360
    if x < 0:
        x += 360
    return x


def request_imu_calibration():
    imu_state["calibrate_requested"] = True


def reset_imu_heading(new_heading=0):
    imu_state["heading"] = _angle_wrap_360(float(new_heading))


def _tof_shutdown_pins():
    try:
        for p in TOF_XSHUT:
            Pin(p, Pin.OUT).value(0)
    except Exception:
        pass


def set_sensor_power(enabled):
    global _sensors_enabled
    _sensors_enabled = bool(enabled)
    sensor_runtime_state["enabled"] = bool(enabled)

    if not _sensors_enabled:
        _tof_shutdown_pins()
        _clear_tof_mm(tof_state["mm"])
        tof_state["ok"] = False
        tof_state["min"] = 0

        imu_state["ok"] = False
        imu_state["heading"] = 0.0
        imu_state["gx_dps"] = 0.0
        imu_state["gy_dps"] = 0.0
        imu_state["gz_dps"] = 0.0
        imu_state["turn_rate_dps"] = 0.0
        imu_state["calibrate_requested"] = False
        imu_state["calibrating"] = False


def start_file_logging(filename="sensor_log.csv", period_ms=100):
    global _log_enabled, _log_fp, _log_period_ms, _log_last_ms, _log_rows_since_flush

    if not ENABLE_SENSOR_FILE_LOGGING:
        _log_enabled = False
        return False

    stop_file_logging()

    _log_period_ms = max(20, int(period_ms))
    _log_last_ms = 0
    _log_rows_since_flush = 0

    _log_fp = open(filename, "w")
    header = ["t_ms", "dt_ms", "hz", "ir_left", "ir_right"]
    for name in TOF_NAMES:
        header.append("tof_" + str(name).lower())
    _log_fp.write(",".join(header) + "\n")
    _log_fp.flush()

    _log_enabled = True
    print("[LOG] file logging started:", filename, "@", _log_period_ms, "ms")
    return True


def stop_file_logging():
    global _log_enabled, _log_fp, _log_rows_since_flush

    _log_enabled = False
    _log_rows_since_flush = 0

    if _log_fp is not None:
        try:
            _log_fp.flush()
        except:
            pass
        try:
            _log_fp.close()
        except:
            pass
        _log_fp = None

    print("[LOG] file logging stopped")

# ======================================================
# IMU Driver
# ======================================================

class LSM6DS3_GyroOnly:
    ADDR = 0x6A
    WHO_AM_I = 0x0F
    CTRL2_G = 0x11

    OUTX_L_G = 0x22
    OUTY_L_G = 0x24
    OUTZ_L_G = 0x26

    SENS = 0.00875

    def __init__(self, i2c):
        self.i2c = i2c
        self._write(self.CTRL2_G, 0x40)
        time.sleep(0.05)
        who = self._read(self.WHO_AM_I)
        print("[IMU] WHO_AM_I =", hex(who))

    def _read(self, reg):
        return self.i2c.readfrom_mem(self.ADDR, reg, 1)[0]

    def _write(self, reg, val):
        self.i2c.writeto_mem(self.ADDR, reg, bytes([val]))

    def read_gyro_xyz_dps_raw(self):
        data = self.i2c.readfrom_mem(self.ADDR, self.OUTX_L_G, 6)
        raw_x, raw_y, raw_z = struct.unpack("<hhh", data)
        return (
            raw_x * self.SENS,
            raw_y * self.SENS,
            raw_z * self.SENS,
        )

# ======================================================
# ToF setup
# ======================================================

def _tof_setup(i2c):
    if not (
        len(TOF_NAMES)
        == len(TOF_XSHUT)
        == len(TOF_ADDRESSES)
        == len(TOF_ENABLED)
    ):
        raise ValueError("ToF config length mismatch")

    xpins = [Pin(p, Pin.OUT) for p in TOF_XSHUT]

    for p in xpins:
        p.value(0)

    time.sleep(0.05)

    sensors = [None] * len(TOF_NAMES)

    for i, (name, p, addr, enabled) in enumerate(zip(TOF_NAMES, xpins, TOF_ADDRESSES, TOF_ENABLED)):
        if not enabled:
            continue

        p.value(1)
        time.sleep(0.08)

        try:
            s = vl53l0x.VL53L0X(i2c, address=0x29)
            s.set_address(addr)
            sensors[i] = s
        except Exception:
            # Drop failed or unused slots back into shutdown so they do not
            # stay alive on the default address and block later sensors.
            p.value(0)

        time.sleep(0.02)

    ready_count = 0
    for i, s in enumerate(sensors):
        if s is None:
            continue
        try:
            s.start()
            ready_count += 1
        except Exception:
            xpins[i].value(0)
            sensors[i] = None

    if ready_count <= 0:
        raise RuntimeError("No ToF sensors initialized")

    return sensors


def _select_heading_rate(gx, gy, gz):
    if HEADING_AXIS == "x":
        return gx
    if HEADING_AXIS == "y":
        return gy
    return gz


def _clear_tof_mm(mm):
    for i in range(len(mm)):
        mm[i] = 0
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
